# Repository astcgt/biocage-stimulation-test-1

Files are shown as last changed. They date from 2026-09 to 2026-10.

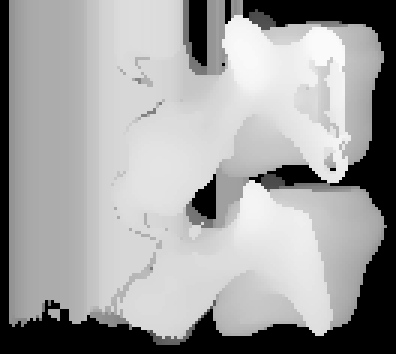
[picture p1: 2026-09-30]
00_prep/proj_ax0_f.png

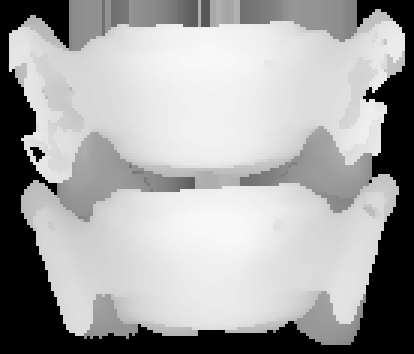
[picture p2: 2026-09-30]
00_prep/proj_ax1_b.png

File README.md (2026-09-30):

# Biocage stimulation test 1

PLCL (Corbion PURASORB PLC 8516, 85:15) contour-matched cages for pig C3/C4 holding a tissue-engineered biodisc.
Two designs: smooth and shoe-tread textured. FEM tests: vertical compression, ASTM F2077-style cyclic
compression (damage + cycle-jump), 6-DOF (100 N preload + escalating moments/shear).
Endpoints: damaged cage volume >15% (10%/20% also reported) or slip >2 mm vs C4.

Background: Lintz 2021 (Cornell) PhD thesis, ch.4 — PLA cages failed posteriorly because of a vertebral bony process.

## Contents
- `input/Pig C3-C4.stl` — source geometry of pig C3/C4 (binary STL).
- `00_prep/` — STL analysis of `Pig C3-C4.stl`: depth projections, disc gap size/height maps, body segmentation.

Status: design and simulation pending GPU and network access.

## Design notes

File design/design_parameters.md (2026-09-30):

| Parameter | Value | Unit |
|---|---|---|
| Target segment | Pig C3/C4 (Gottingen minipig STL) |  |
| Material | Corbion PURASORB PLC 8516 (85:15 L-lactide/e-caprolactone), FDM printed, 37 C |  |
| Footprint (outer) LR x AP | 24.2 x 17.4 | mm |
| Footprint area | 295.6 | mm^2 |
| Vertebral body endplate area | 369.8 | mm^2 |
| Inset from body rim | 1.0 | mm |
| Biodisc window area | 175.8 (59.5% of footprint) | mm^2 |
| Nominal wall thickness | 1.65 | mm |
| Minimum wall thickness | 1.52 | mm |
| Wall (load-bearing) area | 119.9 | mm^2 |
| Height (contour-matched), min / mean / max | 3.06 / 4.15 / 5.86 | mm |
| Upper surface | conforms to C3 caudal endplate (smoothed STL height map) |  |
| Lower surface | conforms to C4 cranial endplate (smoothed STL height map) |  |
| Posterior outline | follows posterior notch and posterolateral uncinate zones with the 1 mm inset |  |
| Cage volume A (smooth) | 498.2 | mm^3 |
| Cage volume B (tread) | 536.0 | mm^3 |
| Tread pattern (B) | chevron/herringbone, arm angle 45.0 deg, apex on midline |  |
| Lug height / width / pitch (B) | 0.4 / 0.8 / 1.6 | mm |
| Lug footprint area per face (B) | 47.3 (39% of wall) | mm^2 |
| Print process | FDM / FFF (filament extrusion), cf. Prusa i3 MK3S+ used for PLA cages in Lintz 2021 ch.4 |  |
| Nozzle / layer / line width | 0.4 / 0.2 / 0.4 | mm |
| Infill | 100 | % |
| XY accuracy | +/-0.1 | mm |
| Nozzle / bed temperature | 190-210 (PLA-class lactide copolymer; tune for PLC 8516) / 40-50 | C |
| Build orientation | cage axis (cranio-caudal) = print Z; layers parallel to endplates |  |
| FE voxel size | 0.2 | mm |

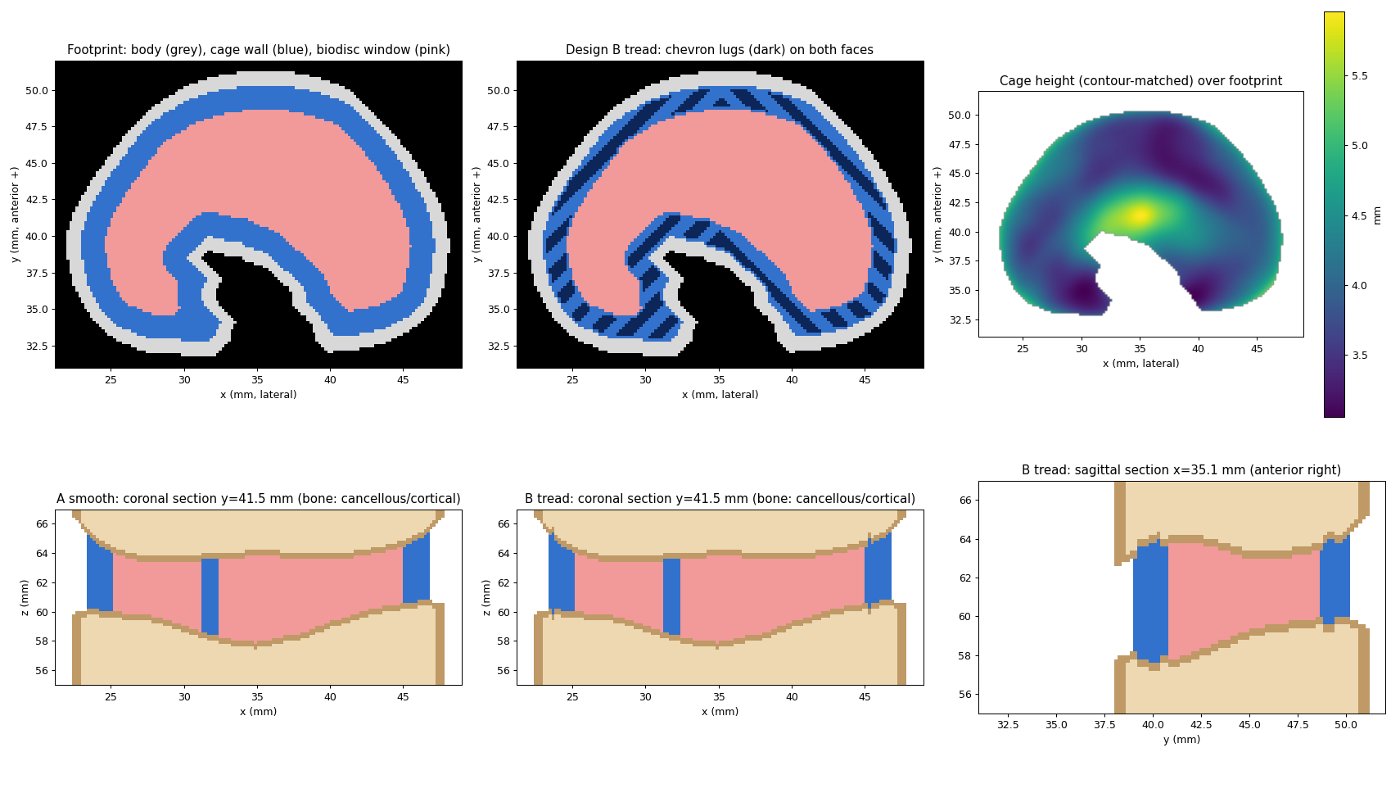
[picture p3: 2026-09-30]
design/design_overview.png

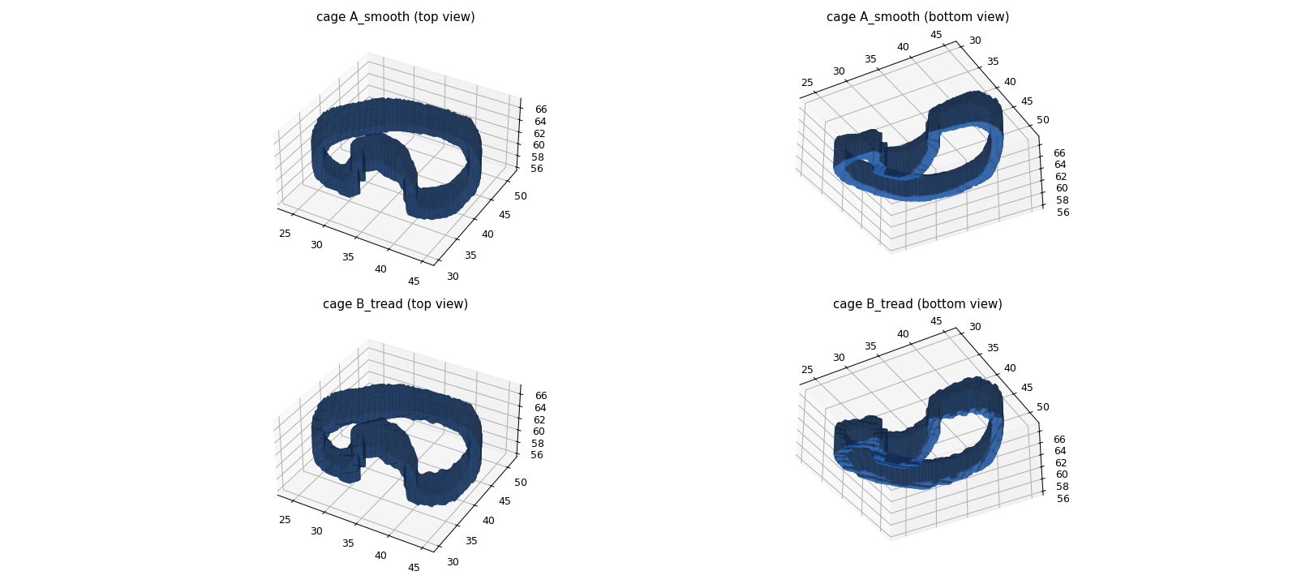
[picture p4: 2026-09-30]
design/cages_3d.png

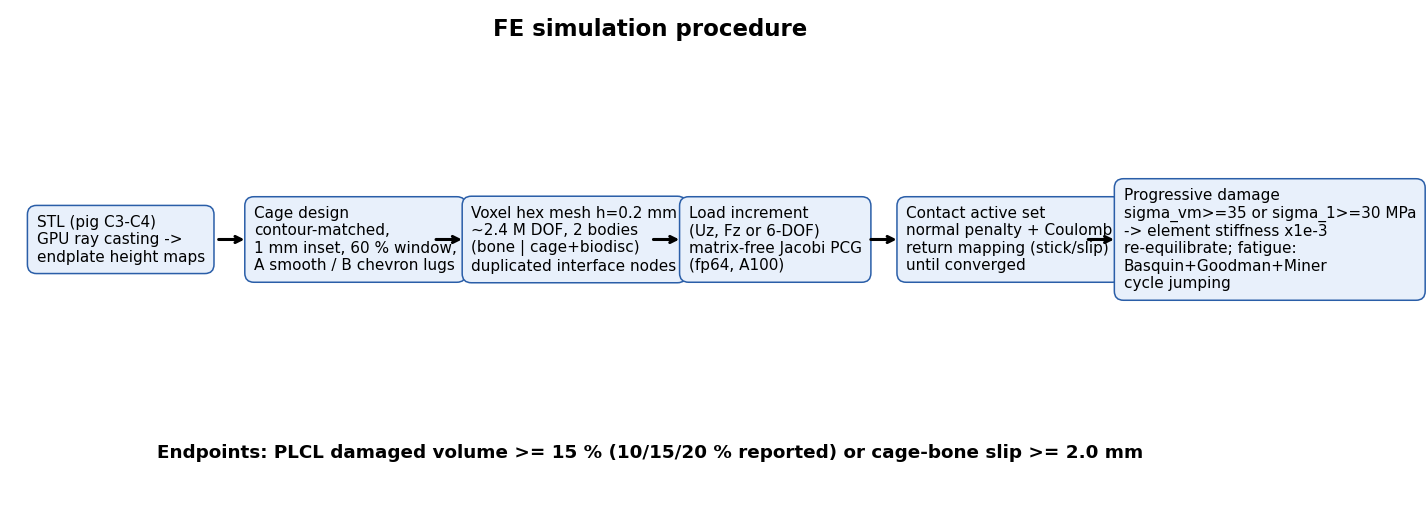
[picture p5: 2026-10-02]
figures/method_flowchart.png

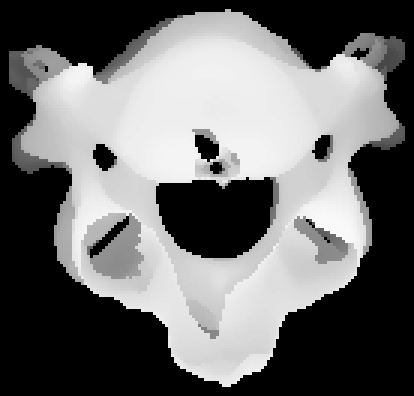
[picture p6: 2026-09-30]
00_prep/proj_ax2_f.png

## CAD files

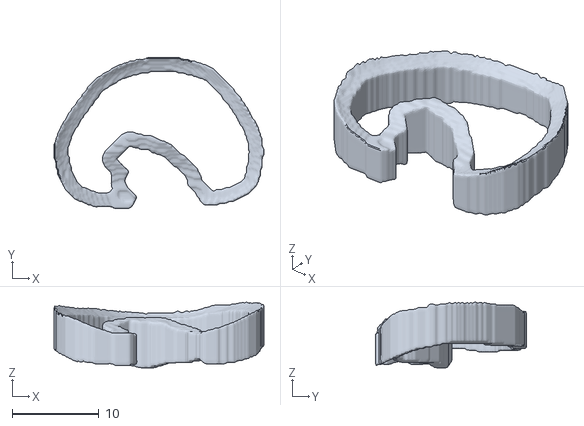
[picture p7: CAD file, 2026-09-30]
design/cage_A_smooth.stl
24.2 x 17.4 x 7.58

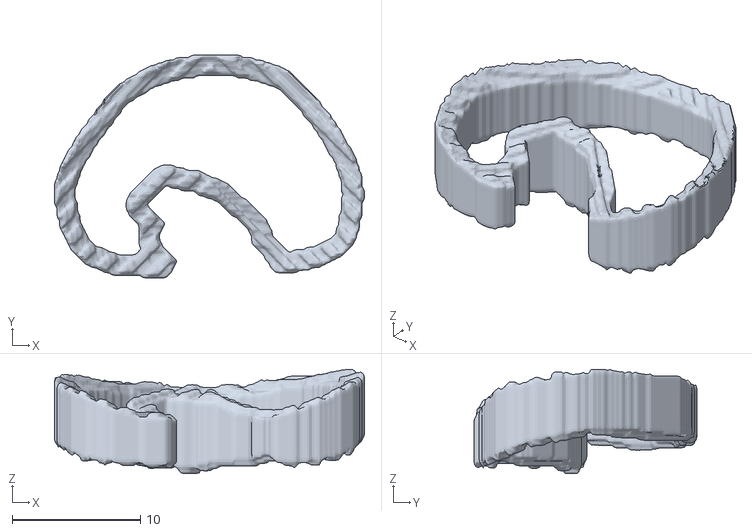
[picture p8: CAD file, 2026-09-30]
design/cage_B_tread.stl
24.2 x 17.4 x 8.14

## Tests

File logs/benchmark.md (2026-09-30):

# GPU parallelisation benchmark (2026-09-30)
Strategy: independent-job parallelism (one FEM case per GPU worker, no domain decomposition).
Parent launched with CUDA_VISIBLE_DEVICES=3,4,7; worker i -> torch.cuda.set_device(i) (cuda:i). GPUs 0,1,2,5,6 belong to another user and were not used.
Workload: 6 linear compression solves (2 designs x 3 displacements), ~2.4 M DOF each, PCG tol 1e-8.

| | 1 GPU (phys 3) | 3 GPUs (phys 3,4,7) |
|---|---|---|
| wall-clock | 106.7 s | 38.9 s |
| speedup | 1.00 | 2.74 |
| SM util (nvidia-smi pmon) | 97 % | 97-98 % each |
| VRAM per process | 2.83 GB (torch peak 1.62 GB) | 2.83 GB each |
| results | reference | bit-identical Fz, max von Mises, PCG iterations |

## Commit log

2026-09-30 Add STL disc-gap analysis and project README
2026-09-30 Add pig C3-C4 source STL
2026-09-30 Add cage designs, GPU contact FE solver, test drivers and GPU pool
    Contour-matched PLCL cages (smooth / chevron tread) from the pig C3-C4 STL,
    voxel hex FE with node-to-node Coulomb contact on the GPU, three test drivers
    (static compression, ASTM F2077-style cyclic, 6-DOF) and an independent-job
    pool across free GPUs, plus the 1- vs 3-GPU benchmark.
    [cage_A_smooth.stl, cage_B_tread.stl, design_parameters.csv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]
2026-09-30 Add per-worker/per-case progress logging for future runs
    Each worker gets its physical GPU id and case number from the pool; the
    three test drivers report step/total, percent, elapsed, ETA and phase to
    line-buffered logs in logs/progress (one per case, one per worker), rate
    limited to every 30 s / 2 % / major phase change. Also includes the
    cyclic-ratchet fix, per-GPU fault-tolerant GPU checks and extended shear.
    Claude-Session: https://claude.ai/code/session_01KcTbBfpWLKLS1gFAgchzG2
2026-10-02 Add test1/test2/test3 results, figures, logs and helper scripts
    [steps.csv]
